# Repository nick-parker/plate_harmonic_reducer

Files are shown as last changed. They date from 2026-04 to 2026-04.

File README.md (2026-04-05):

# Sheet Metal Plate Harmonic Reducer

A 15:1 plate harmonic reducer where every non-turned part is formed sheet metal, designed to be fabricated with a manual lathe and 3D-printed forming dies.

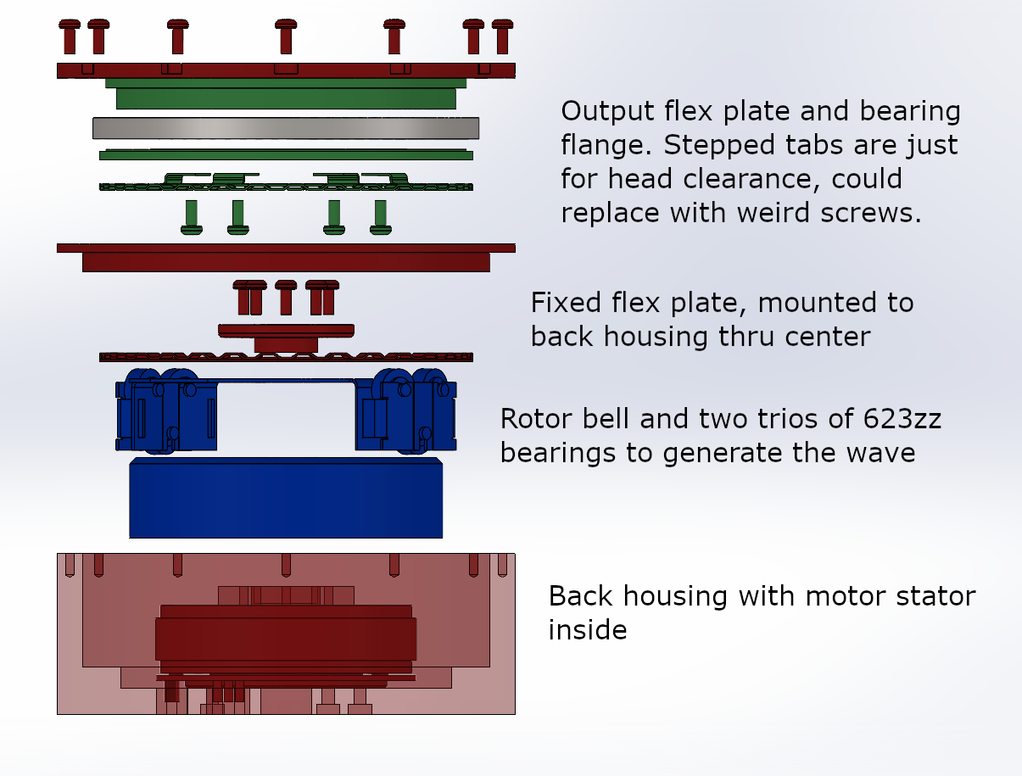
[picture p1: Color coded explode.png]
Exploded view


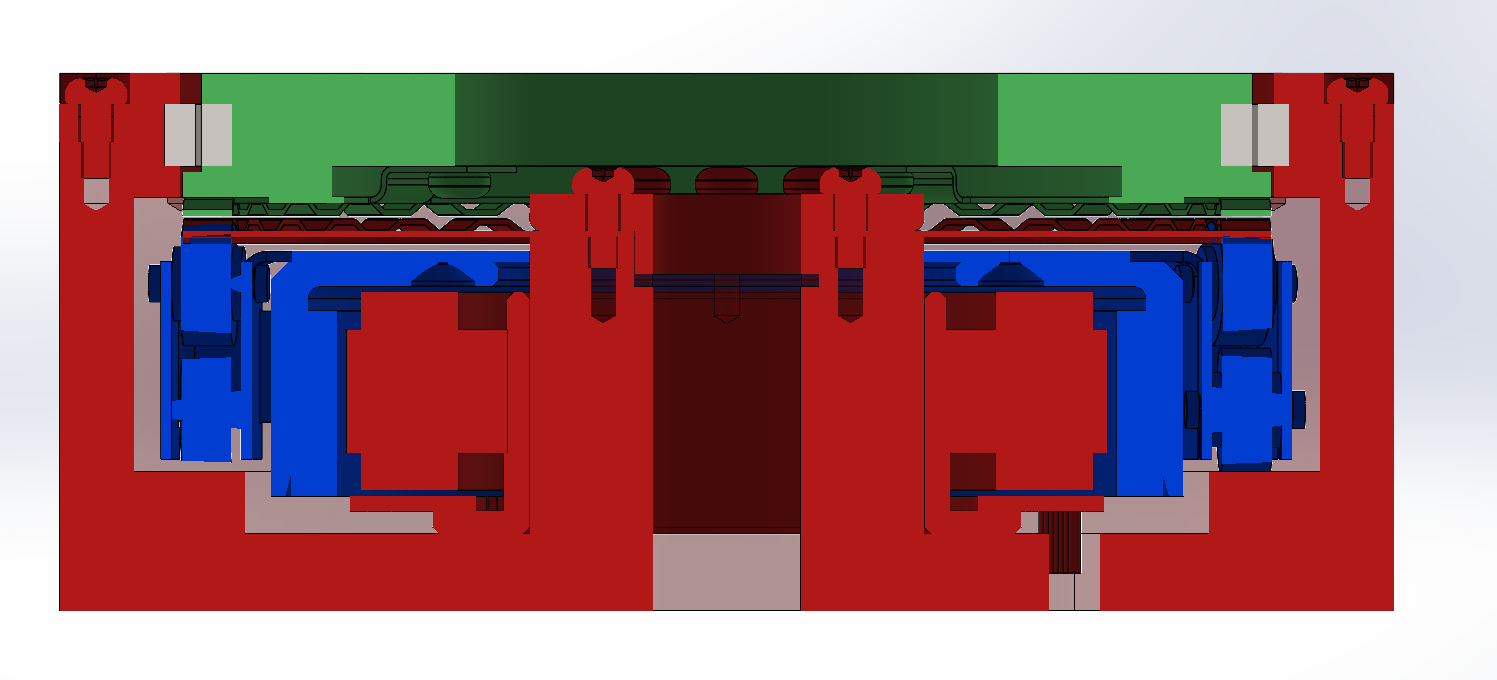
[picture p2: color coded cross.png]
Cross section


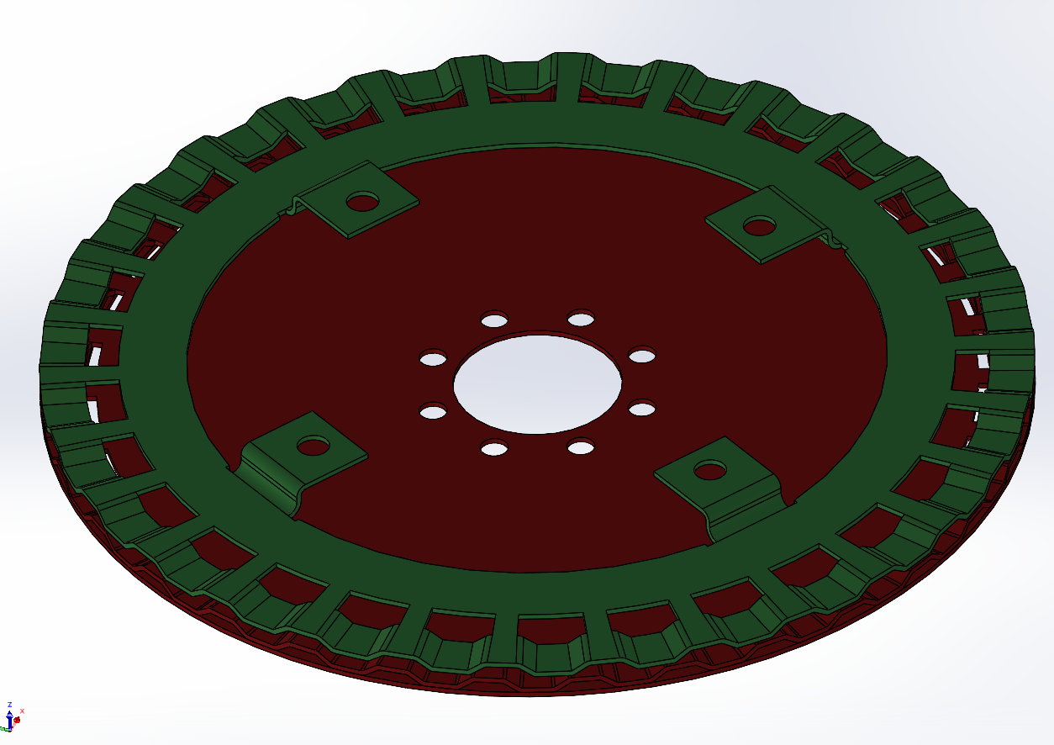
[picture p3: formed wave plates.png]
Wave plates


**Red** = fixed housing + fixed tooth plate (flex spline, 32 teeth). **Blue** = wave generator (input, rides on the motor). **Green** = output gear (30 teeth).

## What is a plate harmonic reducer?

A [plate harmonic reducer](https://doi.org/10.1109/IROS47612.2022.9981317) flattens the conventional cup-shaped flex spline into a thin plate and deforms it axially instead of radially. Same reduction principle (R = Zf/(Zf - Zc)), dramatically lower deformation forces, and — critically for this project — the flex spline is now a flat disc that can be stamped from sheet metal.

The [tri-contact variant](https://doi.org/10.1109/TMECH.2025.3628311) from the same Seoul National University group showed these can operate at low reduction ratios (10:1–30:1) where conventional harmonic drives struggle, with competitive efficiency and backlash. Our design uses a two-contact (two-lobe) wave generator at 32/30 teeth for a 15:1 ratio.

## Why sheet metal everything?

This is inspired by [Peter Holderith](https://twitter.com/_baldtires), who has been developing quick-turn sheet metal forming with 3D-printed dies as a service. The design constraint is: **the only precision operations are rotationally symmetric turning and sheet metal forming with printed tooling.** No surface milling, no wire EDM, no gear cutting. If you have a manual lathe, a 3D printer, and a press, you can make this reducer.

Both the fixed tooth plate (flex spline) and the output tooth plate are formed sheet metal. This is admittedly silly for the output gear — if you own a 3-axis mill, just machine it. But the point is to explore how far sheet metal forming can go as a fabrication strategy for mechanism components.

## Design choices

**Wave generator: roller bearings, not a profiled groove.** The original PHR papers use steel balls riding in a sinusoidal CAM groove to generate the wave. This gives excellent contact ratio but requires precision machining of the groove. Our wave generator instead uses three 623ZZ bearings per lobe — two ride on top of the flex plate to push ~2.5 teeth into engagement, and one transfers that load down onto a running surface on the housing back bell. The original authors avoided rollers because they only engage a narrow arc of teeth and consume axial space. I think wrapping the mechanism around an outrunner motor (eg RO6000 KV115 in CAD now) makes the axial packaging acceptable — the flex plate reducer demands a larger diameter than the motors that match its torque capacity, leaving an annulus of free space around the motor that accommodates tall rollers without growing the overall stack. The rollers should also have better load capacity and easier manufacturing than a precision wavy bearing race.

**Roller supports are sheet metal (and shouldn't be).** The housing is ~6mm wider than necessary because the roller support arms are doubly supported by sheet metal brackets instead of cantilevered features on a machined rotor body. This is a concession to the "sheet metal everything" constraint. A machined rotor with integral roller posts would be the obvious improvement, and could arguably be a manual lathe part if you're brave enough.

**One fastener.** The entire assembly uses a single screw specification: M2.5x6 Torx pan head. The 8x M2.5 holes on the output flange are left empty — use longer bolts to attach your payload.

**Tooth profile.** Trapezoidal teeth with a 35-degree transfer angle (optimized for force transmission per [You et al.](https://doi.org/10.1109/TMECH.2025.3628311)), 1mm tooth height, 4mm radial tooth width, 0.5mm web connecting each tooth to the plate body. 50% duty cycle at mid-tooth-height for balanced root/tip proportions and easier forming.

## Parameters

| Parameter | Value |
|---|---|
| Reduction ratio | 15:1 |
| Fixed tooth plate (flex spline) | 32 teeth |
| Output tooth plate | 30 teeth |
| Pitch diameter | 42mm |
| Tooth height | 1mm |
| Transfer angle | 35 deg |
| Web thickness | 0.5mm |
| Motor | RO6000 KV115 (or similar outrunner) |
| Bearing | CRBT8050 (Chinese thin cross roller) |

## References

1. S. You, J. Jung, E. Sung, and J. Park, "Plate Harmonic Reducer with a Profiled Groove Wave Generator," *IEEE/RSJ IROS*, 2022. [DOI: 10.1109/IROS47612.2022.9981317](https://doi.org/10.1109/IROS47612.2022.9981317) | [pdf](http://dyros.snu.ac.kr/wp-content/uploads/2022/11/76347-3462.pdf?ckattempt=1)

2. S. You, E. Sung, D. Kim, J. Kim, and J. Park, "Semidirect Drive Based on Tri-Contacted Plate Harmonic Reducer," *IEEE/ASME Trans. Mechatronics*, 2025. [DOI: 10.1109/TMECH.2025.3628311](https://doi.org/10.1109/TMECH.2025.3628311)

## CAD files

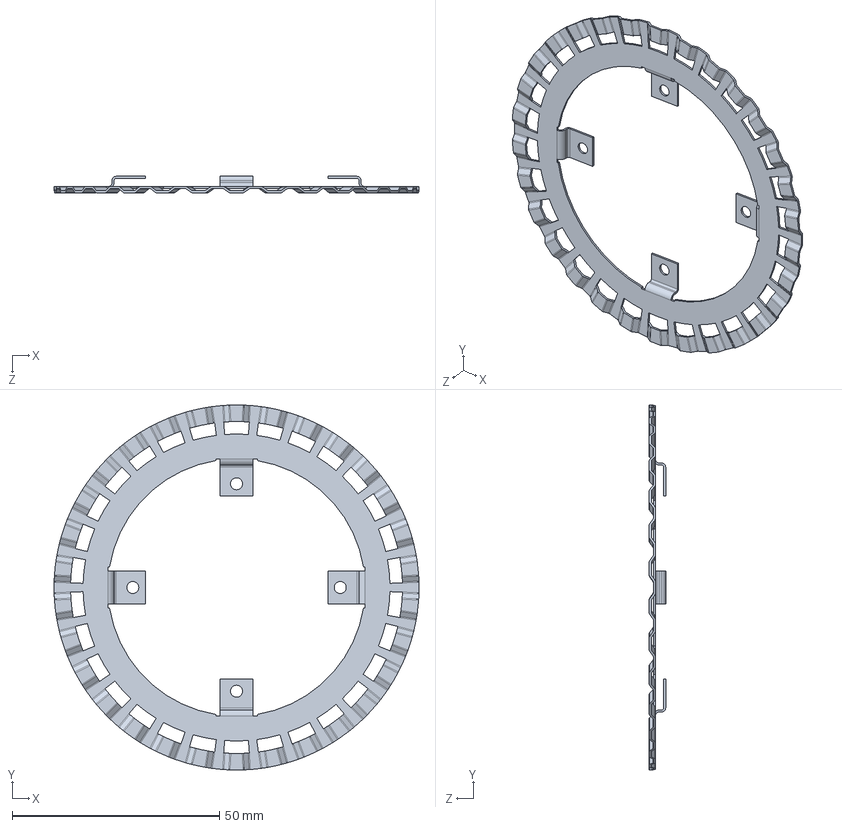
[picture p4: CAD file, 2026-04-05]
output tooth plate.SLDPRT
88.0 x 88.0 x 4.00 mm

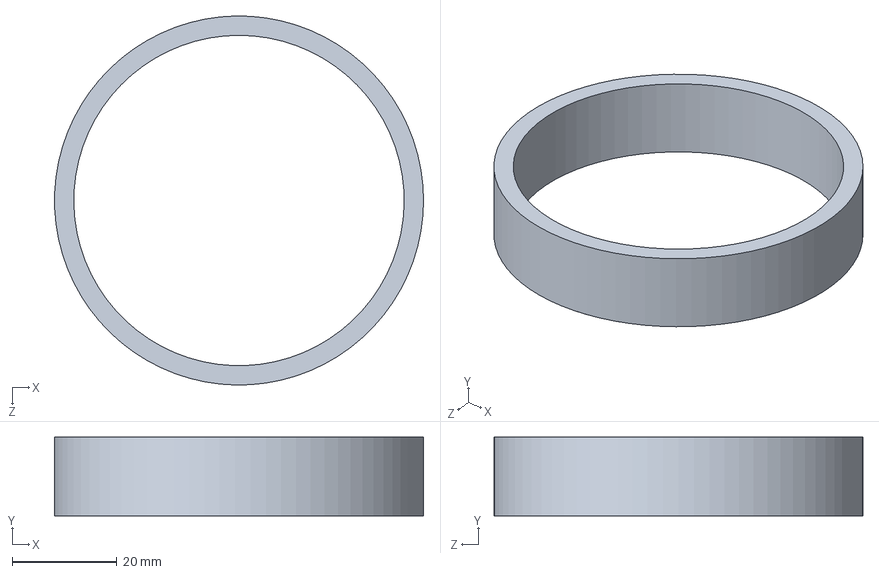
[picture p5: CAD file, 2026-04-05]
RO6000 Rotor Magnets.SLDPRT
70.5 x 15.0 x 70.5 mm

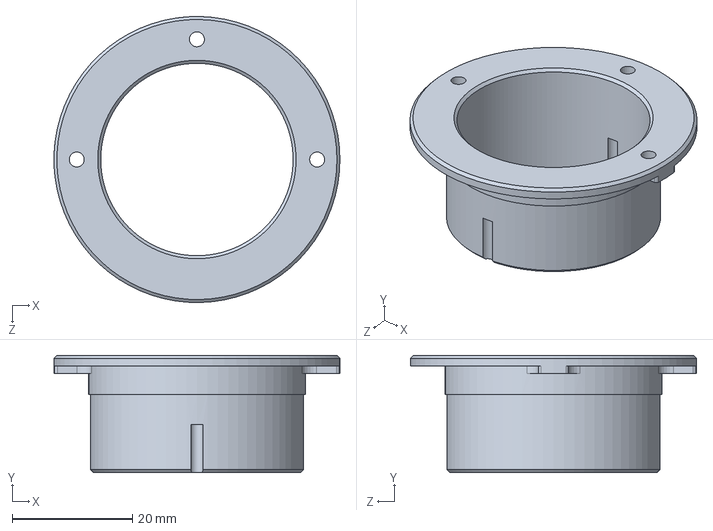
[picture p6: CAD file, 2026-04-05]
RO6000 Stator Core.SLDPRT
47.6 x 19.5 x 47.6 mm

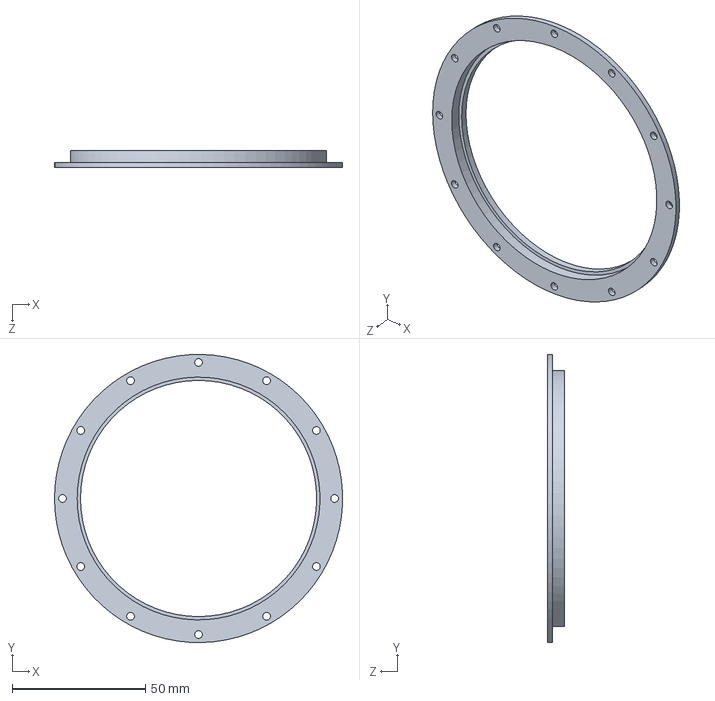
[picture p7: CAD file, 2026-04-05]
housing.SLDPRT
108.0 x 108.0 x 6.50 mm

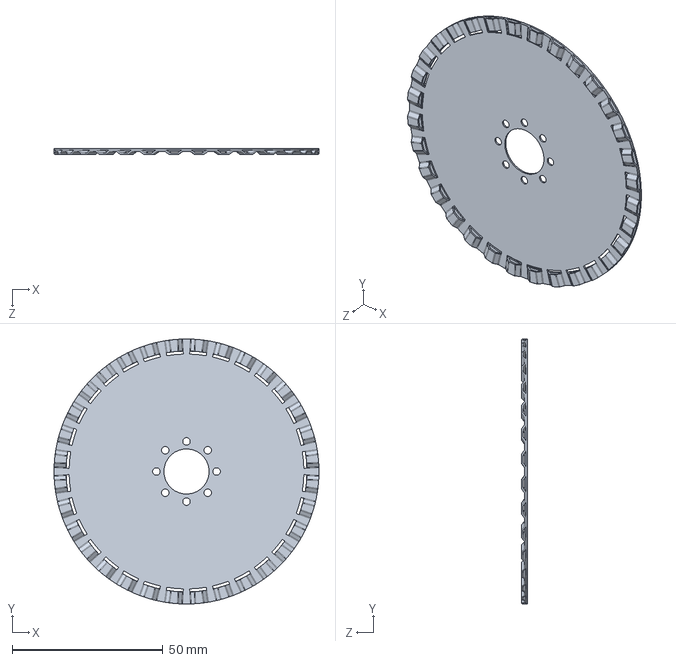
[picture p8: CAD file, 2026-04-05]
flex plate.SLDPRT
88.0 x 88.0 x 2.01 mm

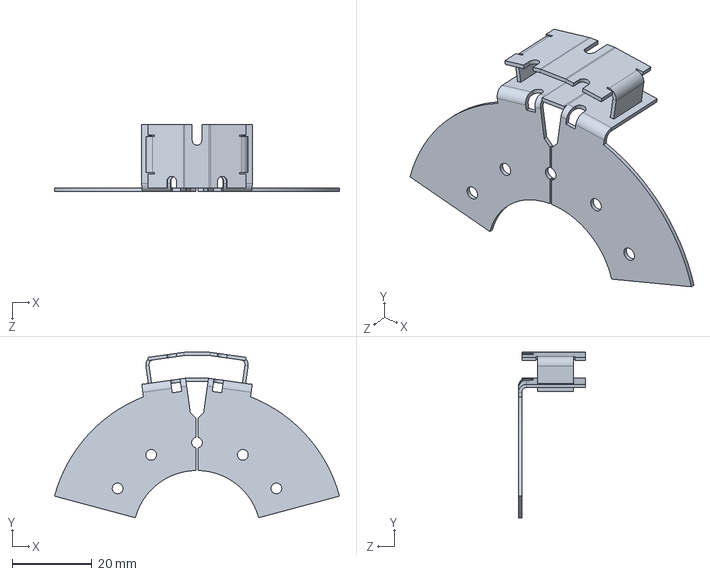
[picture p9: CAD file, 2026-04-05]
wave generator sandwich.SLDPRT
71.5 x 41.5 x 16.8 mm

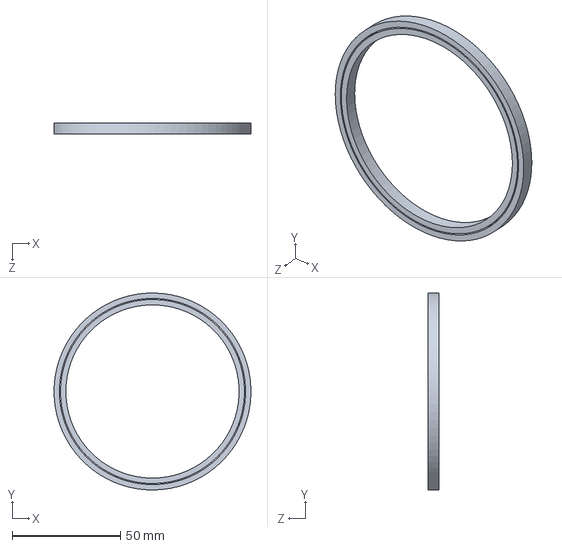
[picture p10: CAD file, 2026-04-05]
CRBT805A Bearing.SLDPRT
91.0 x 91.0 x 5.00 mm

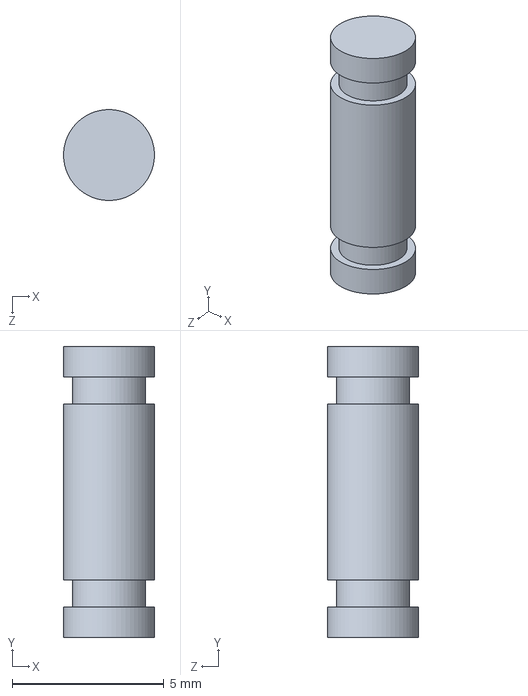
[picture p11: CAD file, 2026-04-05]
wave bearing pin.SLDPRT
3.00 x 9.60 x 3.00 mm

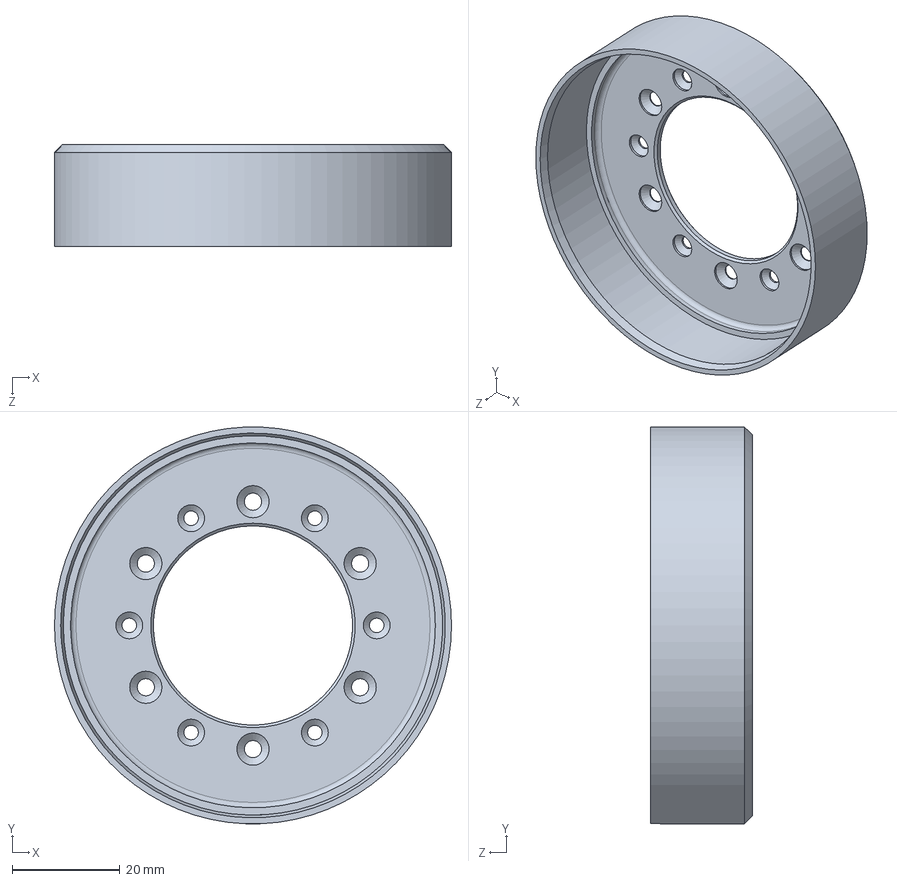
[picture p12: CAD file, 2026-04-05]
RO6000 Rotor.SLDPRT
73.8 x 73.8 x 19.0 mm

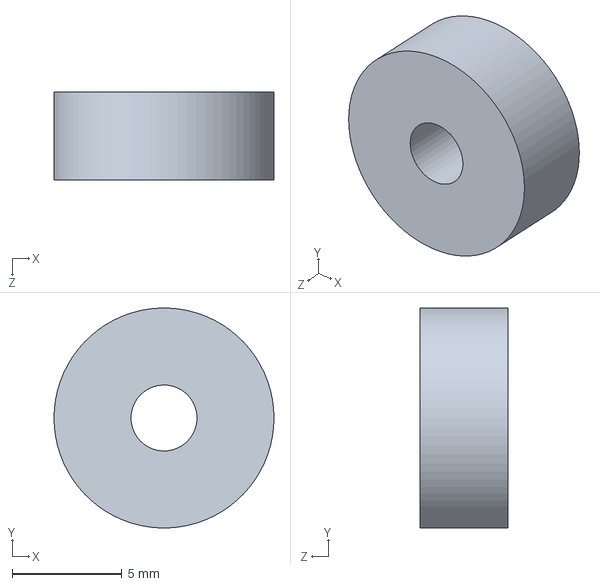
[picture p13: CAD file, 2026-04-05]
623zz bearing.SLDPRT
10.0 x 9.99 x 4.00 mm

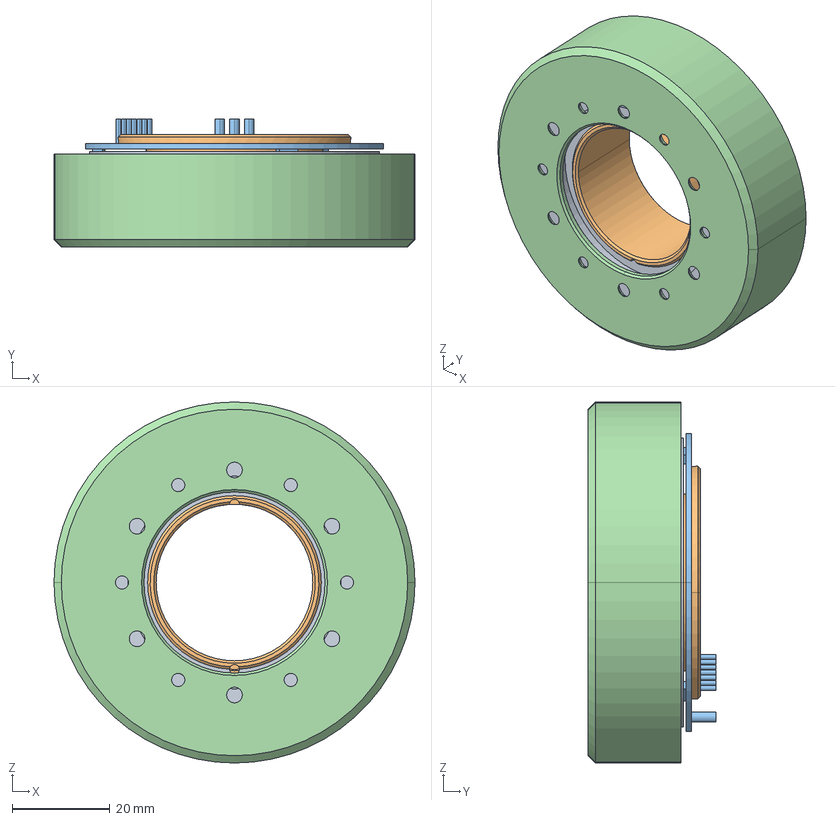
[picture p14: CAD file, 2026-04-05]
RO60_KV115.stp
73.8 x 26.2 x 73.8 mm
R06000_7
RO6000_17
RO60PCB_12
RO6000_12
RO6000_5

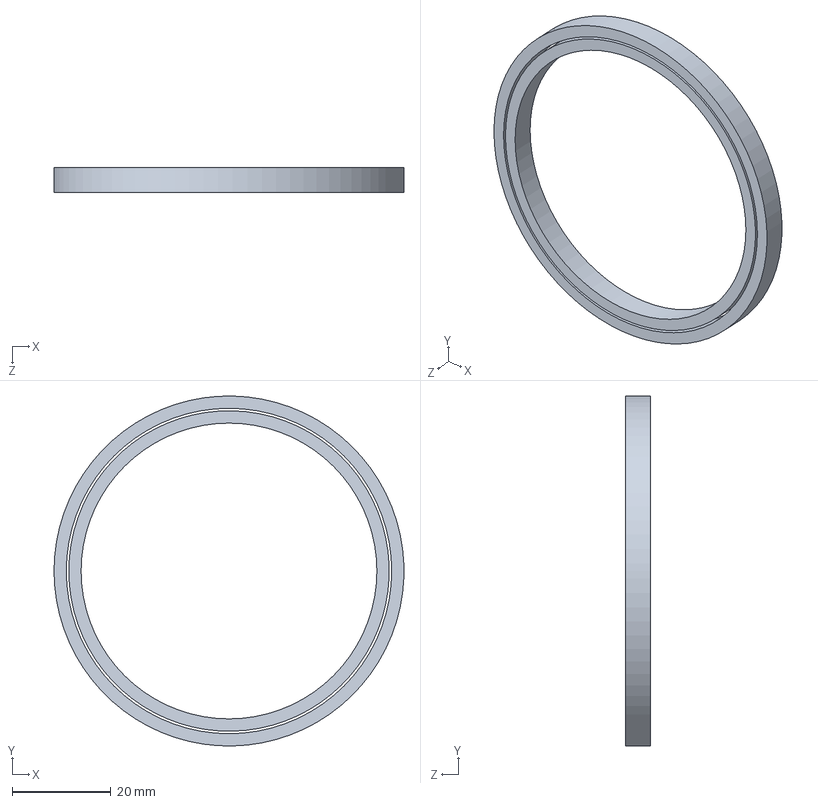
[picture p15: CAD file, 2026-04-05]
CRBT605A Bearing.SLDPRT
71.0 x 71.0 x 5.00 mm

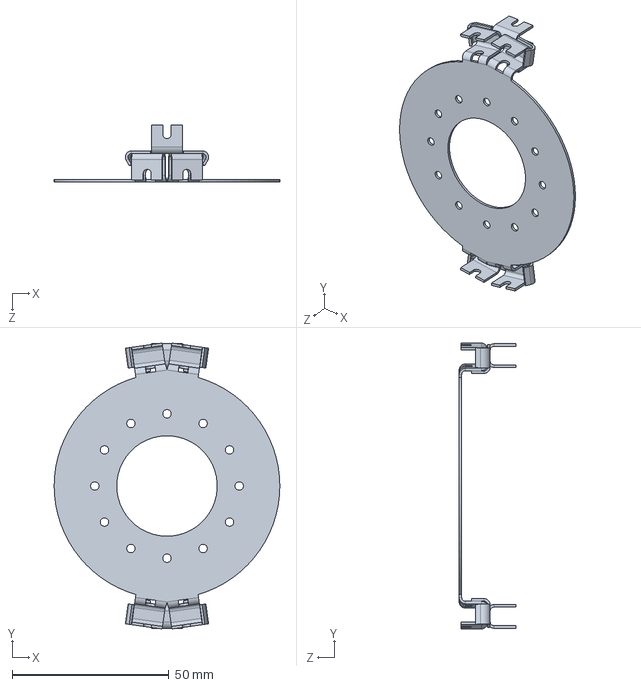
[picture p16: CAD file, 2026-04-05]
wave generator.SLDPRT
71.9 x 91.1 x 18.1 mm

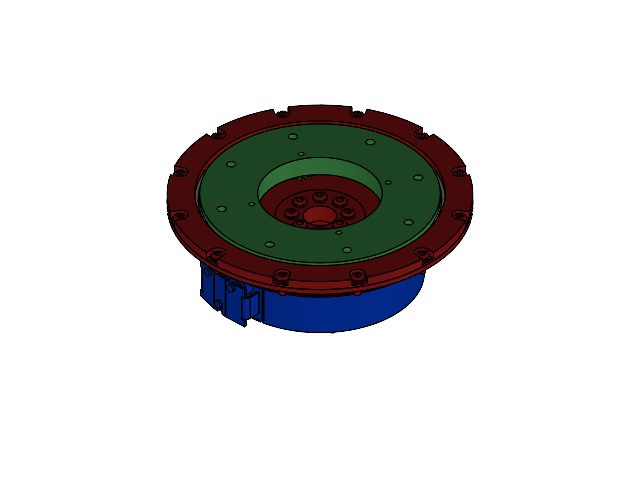
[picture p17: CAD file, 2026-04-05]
PHR.SLDASM
flex plate
CRBT805A Bearing
R06000 Stator Windings
RO6000 Stator Core
RO60PCB_12
RO6000 Rotor
RO6000 Rotor Magnets
623zz bearing x 6
wave bearing pin x 6
wave bearing shim washer x 12
wave generator sandwich x 2
output flange x 2
output tooth plate
90362A145_18-8 Stainless Steel Pan Head Torx Screws x 24
housing x 3

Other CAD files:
Rotor.SLDASM
output flange.SLDASM
wave bearing with pin.SLDASM
layout.SLDPRT
90362A145_18-8 Stainless Steel Pan Head Torx Screws.SLDPRT
R06000 Stator Windings.SLDPRT
R06000_7.SLDPRT
RO6000_12.SLDPRT
RO6000_17.SLDPRT
RO6000_5.SLDPRT
RO60PCB_12.SLDPRT
RO60_KV115.SLDASM
fixed tooth plate.SLDPRT
output flange.SLDPRT
rotor.SLDPRT
wave bearing shim washer.SLDPRT
